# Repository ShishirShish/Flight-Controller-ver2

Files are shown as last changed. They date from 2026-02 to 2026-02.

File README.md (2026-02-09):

🛩️ SEC Flight Controller (Dual-Computer Architecture)

This repository contains the hardware design of a second-generation (SEC) Flight Controller, featuring a dual-microcontroller architecture with clear separation between real-time flight control and navigation / sensor processing.
The design emphasizes determinism, fault isolation, clean power domains, and scalable peripherals, inspired by aerospace and safety-critical embedded systems.

🧠 System Architecture Overview
Battery / Power
      |
      v
+------------------+
| Power Management |
+------------------+
        |
        +-------------------+
        |                   |
        v                   v
+----------------+   +----------------+
| Flight Control |   | Navigation     |
| Computer (FCC) |<->| Computer (NAVC)|
+----------------+   +----------------+
        |                   |
        v                   v
   Actuators / PWM       Sensors / GPS

🔹 Major Subsystems

1️⃣ Power Subsystem
Battery input up to 26 V
Precision current sense resistor (10 mΩ)
INA219 voltage / current / power monitoring (I²C)
High-current buck regulator (5 V rail)
Dedicated 3.3 V LDO for digital and sensor domains
SGND / PGND separation for noise control
Power-good, enable, and status monitoring

2️⃣ Flight Control Computer (FCC)

Role:
Real-time flight control, actuator outputs, and deterministic tasks.

MCU:
STM32F2 / STM32F4-class MCU
Key Responsibilities
PWM generation for ESCs / servos
Hard real-time control loops
Command interface to NAVC
External SPI flash for logging/config
EEPROM for configuration storage

Key Interfaces
UART (FCC ↔ NAVC)
I²C (shared / isolated buses)
SPI (external flash)
USB (programming + debug)
SWD debug header

3️⃣ Navigation Computer (NAVC)

Role:
Sensor fusion, navigation, and high-level state estimation.

MCU:
STM32F405RG-class MCU
Connected Sensors
IMU (Accelerometer + Gyroscope)
Magnetometer
Absolute pressure sensor (barometer)
Temperature sensor
GNSS (u-blox MAX-8Q)

Key Features
Dedicated sensor I²C bus
Interrupt-driven IMU & MAG
GNSS backup battery support
Independent boot and reset control
Debug UART via USB-to-UART bridge

🔁 FCC ↔ NAVC Communication
UART (bi-directional command & telemetry)
I²C (optional shared peripherals)
GPIO handshake lines
Series resistors for signal integrity and isolation

This separation allows:
Deterministic control on FCC
Computationally heavier navigation on NAVC
Easier fault containment and debugging

🔌 Peripherals & Interfaces
FCC Peripherals
PCA9685 PWM driver (16-channel)
External SPI flash memory
I²C EEPROM
Multiple UART expansion headers
ADC inputs
Servo / ESC connectors (5 V tolerant)
NAVC Peripherals
IMU + Magnetometer
Barometer + Temperature sensor
GNSS module with SMA antenna
EEPROM
Debug and telemetry UARTs

🧪 Clocking & Reset Strategy
High-speed external crystals (25 MHz) for both MCUs
Separate reset switches for FCC and NAVC
Boot-mode selection via hardware switches
Internal NRST pull-ups used where applicable

🛠️ Programming & Debug
USB-FS programming support
Dedicated SWD headers for FCC and NAVC
USB-to-UART bridges for runtime debug
Jumper-selectable USB VBUS routing

📐 Design Considerations
Clear power-domain separation
Extensive local decoupling
Ferrite bead filtering for VDDA
Series resistors on inter-MCU signals
EMI-aware sensor and GNSS routing
Designed with flight safety and expandability in mind

🧰 Tools Used
KiCad EDA 9.0.6
STM32 Reference Manuals & AN2606
Sensor manufacturer datasheets
Aerospace-style schematic partitioning

🚀 Intended Applications
Advanced UAV / drone platforms
Research flight controllers
Navigation & sensor-fusion experimentation
Safety-critical embedded system studies
FCC / NAVC split-architecture learning

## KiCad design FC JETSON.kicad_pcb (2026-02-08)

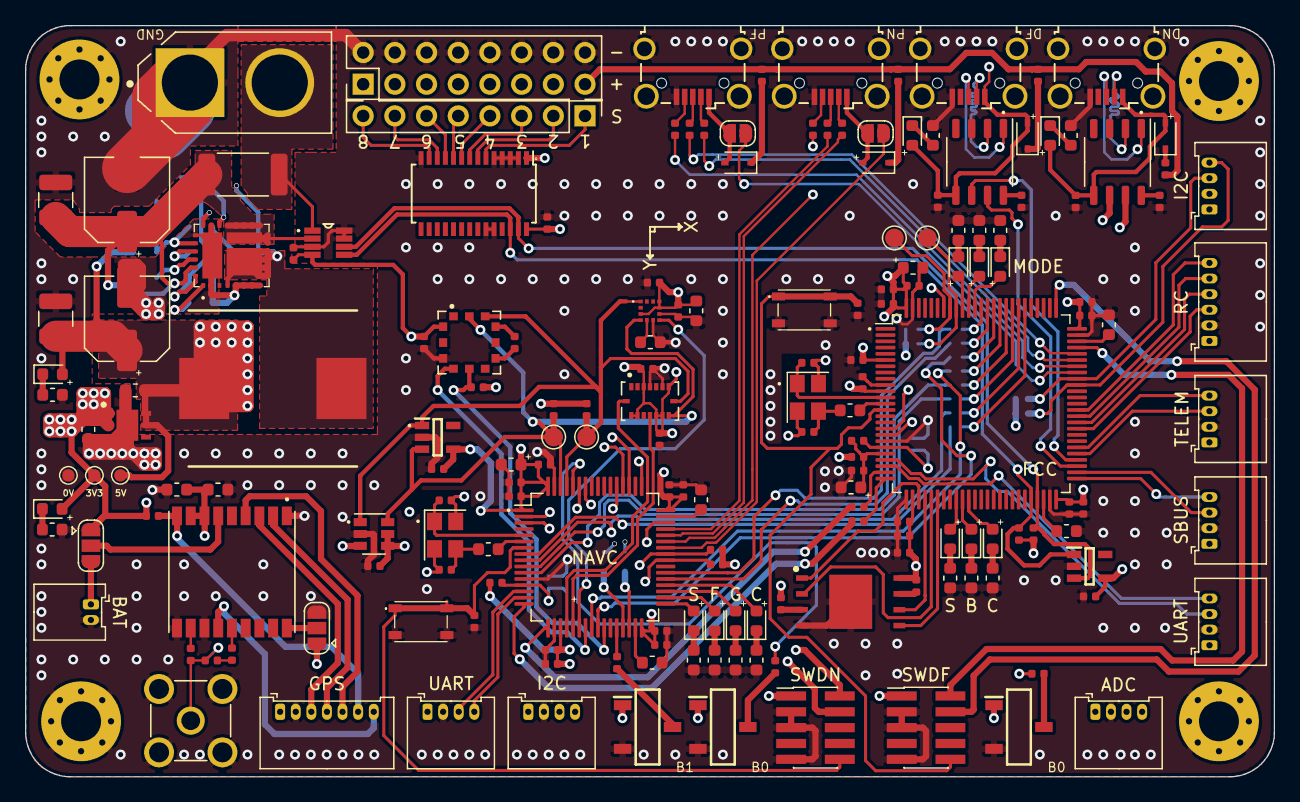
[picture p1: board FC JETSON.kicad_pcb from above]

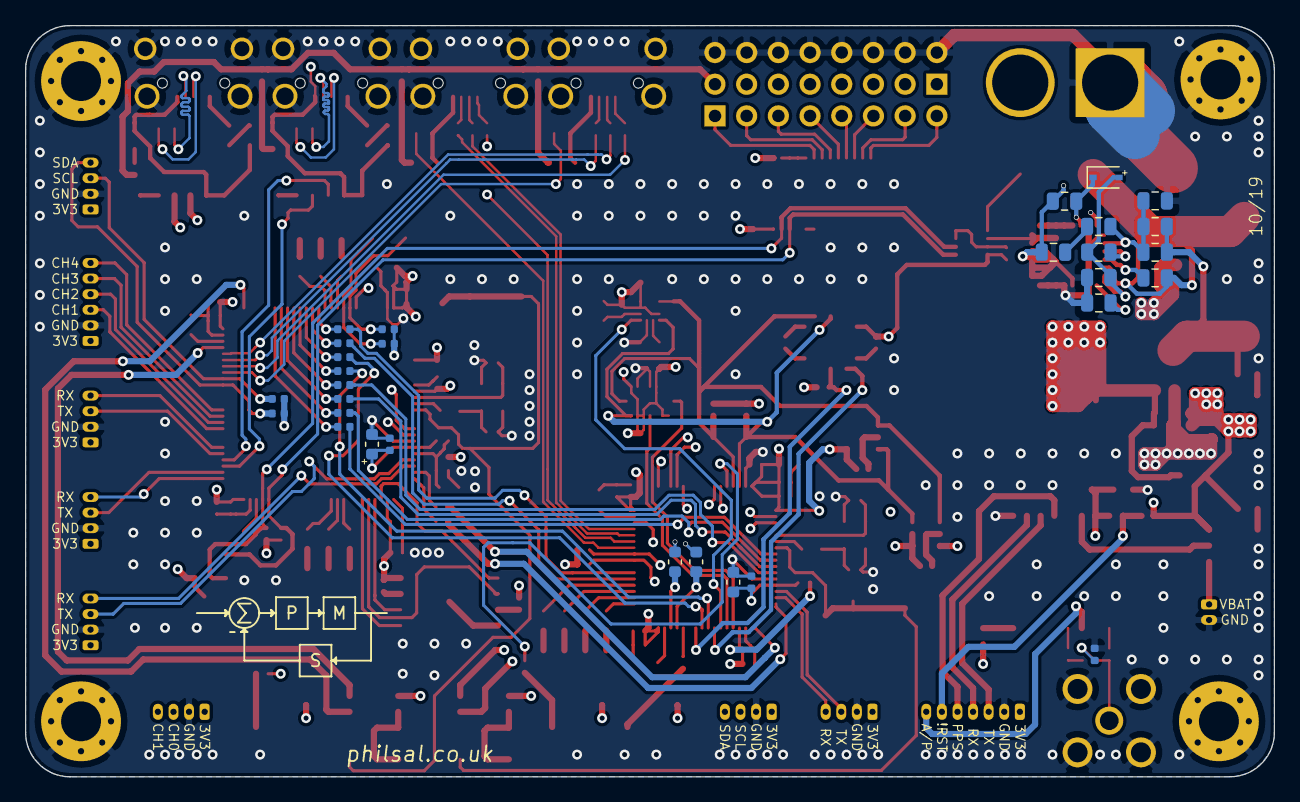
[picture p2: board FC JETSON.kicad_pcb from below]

Board: 4 copper layers, 100.1 x 60.2 mm, 211 parts (30 on the bottom side), 174 nets.

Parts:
5V, 5V#2, 5V#3: TestPoint_Pad_D1.0mm
ADC: Conn_01x04; Molex_PicoBlade_53048-0410_1x04_P1.25mm_Horizontal
ANT1: 5-1814832-1; TE_5-1814832-1
BAT: Conn_01x02; Molex_PicoBlade_53048-0210_1x02_P1.25mm_Horizontal
BAT1: XT60-M; AMASS_XT60-M
C1, C8: 100u; C_Elec_6.3x7.7
C2, C9: 47u; C_1210_3225Metric
C3, C4: 2u2; C_0805_2012Metric
C5, C6: 100n; C_0805_2012Metric
C7: 4n7; C_0805_2012Metric
C10, C16, C17, C18, C19, C20, C21, C22, C23, C24, C25, C26, C28, C30, C31, C34, C35, C36, C40, C41, C42, C43, C44, C45, C46, C47, C48, C49, C51, C54, C55, C56, C58, C60, C61, C63, C68, C69, C70, C71: 100n; C_0402_1005Metric
C11, C12, C15, C39, C62: 10u; C_0603_1608Metric
C13, C14, C37, C38: 2u2; C_0603_1608Metric
C27, C29, C50, C64, C65: 1u; C_0603_1608Metric
C32, C33, C52, C53: 10p; C_0402_1005Metric
C57: 1n; C_0402_1005Metric
C59: 220n; C_0603_1608Metric
C66: 22p; C_0402_1005Metric
C67: 10n; C_0402_1005Metric
D1, D2, D3, D4, D5: SD103AWS; D_SOD-323
FB1, FB2, FB3, FB4, FB5, FB6: Ferrite_Bead_Small; L_0402_1005Metric
FCC: STM32H753VITx; LQFP-100_14x14mm_P0.5mm
GPS: Conn_01x07; Molex_PicoBlade_53048-0710_1x07_P1.25mm_Horizontal
HSE1, HSE2: 25MHz; Crystal_SMD_Abracon_ABM8G-4Pin_3.2x2.5mm
I2C, I2C#2: Conn_01x04; Molex_PicoBlade_53048-0410_1x04_P1.25mm_Horizontal
JP1, JP2: SolderJumper_2_Open; SolderJumper-2_P1.3mm_Open_RoundedPad1.0x1.5mm
JP3: SolderJumper_3_Open; SolderJumper-3_P1.3mm_Open_RoundedPad1.0x1.5mm
JP4: Jumper_3_Open; SolderJumper-3_P1.3mm_Open_RoundedPad1.0x1.5mm
L1: 15u; INDPM135125X650N
L2: 27n; L_0402_1005Metric
LED1, LED2, LED13, LED14: G; LED_0603_1608Metric
LED3, LED4, LED9, LED10: R; LED_0603_1608Metric
LED5, LED11: Y; LED_0603_1608Metric
LED6, LED7, LED8, LED12: B; LED_0603_1608Metric
NAVC: STM32F405RGTx; LQFP-64_10x10mm_P0.5mm
PWM_POW1: Conn_02x08_Odd_Even; PinHeader_2x08_P2.54mm_Vertical
PWM_SIG1: 2.54mm; PinHeader_1x08_P2.54mm_Vertical
R1: 0.01; R_2512_6332Metric
R2, R3: 10k; R_0805_2012Metric
R4: 19k6; R_0805_2012Metric
R5: 6k8; R_0805_2012Metric
R6: 1k3; R_0805_2012Metric
R7, R58, R59: 560; R_0603_1608Metric
R8: 240; R_0603_1608Metric
R9, R10, R11, R12, R13, R14, R28, R29, R30, R31: 4k7; R_0402_1005Metric
R15, R16, R17, R33, R34, R35: 330; R_0603_1608Metric
R18, R19, R20, R36: 100; R_0603_1608Metric
R21: 47; R_0402_1005Metric
R22, R24, R25, R26, R27, R37, R38: 10k; R_0402_1005Metric
R23, R32: 620; R_0603_1608Metric
R39, R40, R41, R42, R43, R44, R45, R46, R47, R48, R49: 10; R_0402_1005Metric
R50, R51: 0; R_0603_1608Metric
R52, R53, R55, R56: 22; R_0402_1005Metric
R54, R57: 560; R_0402_1005Metric
RC: Conn_01x06; Molex_PicoBlade_53048-0610_1x06_P1.25mm_Horizontal
REG1: MIC26903YJL-TR; MIC24054YJLTR
REG2: LD39200PU33R; SON95P300X300X100-7N-D
SBUS: Conn_01x04; Molex_PicoBlade_53048-0410_1x04_P1.25mm_Horizontal
SW1, SW5: SKRPANE010; SKRPADE010
SW2, SW3, SW4: TDD01H0SB1R; SOT175P420X230-3N
SWDF: Conn_02x05_Odd_Even; PinHeader_2x05_P1.27mm_Vertical_SMD
SWDN: Conn_02x05_Odd_Even; PinHeader_2x05_P1.27mm_Vertical_SMD
TELEM: Conn_01x04; Molex_PicoBlade_53048-0410_1x04_P1.25mm_Horizontal
TP1, TP2, TP3, TP4: I2C1; TestPoint_Pad_D1.5mm
U1: INA219AIDCNR; SOT65P280X145-8N
U2: PCA9685PW; TSSOP-28_4.4x9.7mm_P0.65mm
U3, U9: 24CW1280T-I_OT; SOT95P280X145-5N
U4: W25N01GVZEIG_TR; SON127P800X600X80-9N-D
U5: BMI088; PQFN50P450X300X100-16N
U6: TMP100; SOT-23-6
U7: MPRLS0025PA00001A; XDCR_MPRLS0025PA00001A
U8: IIS2MDCTR
U10: u-blox MAX-8Q; GPS18P-SMD-1.1-10X9.6MM
U11, U12: otter:CH330; SSOP-8_3.9x5.05mm_P1.27mm
UART: Conn_01x04; Molex_PicoBlade_53048-0410_1x04_P1.25mm_Horizontal
UART#2: Conn_01x04; Molex_PicoBlade_53048-0410_1x04_P1.25mm_Horizontal
USB1, USB2, USB3, USB4: USB_B_Micro; USB_Micro-B_Wuerth_629105150521_CircularHoles

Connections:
+3V3: 5V#2.1, ADC.1, C10.1, C12.1, C15.1, C16.1, C17.1, C18.1, C19.1, C20.1, C21.1, C22.1, C23.1, C24.1, C25.1, C26.1, C34.1, C35.1, C36.2, C39.1, C40.1, C41.1, C42.1, C43.1, C44.1, C45.1, C46.1, C47.1, C48.1, C54.1, C55.1, C56.1, C58.1, C60.1, C61.1, C62.1, C63.1, C64.1, C65.1, FB1.2, FB2.2, FCC.6, FCC.11, FCC.27, FCC.50, FCC.75, FCC.100, GPS.1, I2C.1, I2C#2.1, JP3.1, JP4.1, LED2.2, NAVC.1, NAVC.19, NAVC.32, NAVC.48, NAVC.64, R9.1, R10.1, R11.1, R12.1, R13.1, R14.1, R24.1, R25.1, R28.1, R29.1, R30.1, R31.1, R37.1, R38.1, RC.1, REG2.1, REG2.2, SBUS.1, SW2.1, SW3.1, SW4.1, SWDF.1, SWDN.1, TELEM.1, U1.4, U2.1, U2.28, U3.4, U4.8, U5.3, U5.7, U5.10, U5.11, U5.14, U5.15, U6.3, U6.4, U6.5, U7.12, U8.3, U8.9, U8.10, U9.4, U10.7, U10.8, UART.1, UART#2.1
+5V: 5V.1, C7.1, C8.1, C9.1, C11.1, FB3.1, FB4.1, FB5.1, FB6.1, L1.2, LED1.2, PWM_POW1.1, PWM_POW1.3, PWM_POW1.5, PWM_POW1.7, PWM_POW1.9, PWM_POW1.11, PWM_POW1.13, PWM_POW1.15, R5.1, REG2.5, REG2.6
ADC3_0_FCC: ADC.3, FCC.17
ADC3_1_FCC: ADC.4, FCC.18
BAR_NRST_NAVC: NAVC.26, R37.2, U7.8
BOOT0_FCC: FCC.94, R22.2
BOOT0_NAVC: NAVC.60, R26.2
BOOT1_NAVC: NAVC.28, R27.2
GND: 5V#3.1, ADC.2, ANT1.2, ANT1.3, ANT1.4, ANT1.5, BAT.2, BAT1.1, C1.2, C2.2, C3.2, C4.2, C8.2, C9.2, C10.2, C11.2, C12.2, C13.2, C14.2, C15.2, C16.2, C17.2, C18.2, C19.2, C20.2, C21.2, C22.2, C23.2, C24.2, C25.2, C26.2, C27.2, C28.2, C29.2, C30.2, C31.2, C32.2, C33.2, C34.2, C35.2, C36.1, C37.2, C38.2, C39.2, C40.2, C41.2, C42.2, C43.2, C44.2, C45.2, C46.2, C47.2, C48.2, C49.2, C50.2, C51.2, C52.2, C53.2, C54.2, C55.2, C56.2, C58.2, C59.2, C60.2, C61.2, C62.2, C63.2, C64.2, C65.2, C67.2, C68.1, C69.1, C70.1, C71.1, FCC.10, FCC.19, FCC.26, FCC.49, FCC.74, FCC.99, GPS.2, HSE1.2, HSE1.4, HSE2.2, HSE2.4, I2C.2, I2C#2.2, JP3.3, NAVC.12, NAVC.18, NAVC.63, PWM_POW1.2, PWM_POW1.4, PWM_POW1.6, PWM_POW1.8, PWM_POW1.10, PWM_POW1.12, PWM_POW1.14, PWM_POW1.16, R6.1, R7.1, R8.1, R15.1, R16.1, R17.1, R18.1, R19.1, R20.1, R33.1, R34.1, R35.1, R36.1, R58.1, R59.1, RC.2, REG1.2, REG1.5, REG1.6, REG1.7, REG1.8, REG1.21, REG1.23, REG1.31, REG2.3, REG2.7, SBUS.2, SW1.3, SW1.4, SW2.2, SW3.2, SW4.2, SW5.3, SW5.4, SWDF.3, SWDF.5, SWDF.9, SWDN.3, SWDN.5, SWDN.9, TELEM.2, U1.3, U1.7, U1.8, U2.2, U2.3, U2.4, U2.5, U2.14, U2.23, U2.24, U3.2, U4.4, U4.9, U5.4, U5.6, U6.2, U7.10, U8.6, U8.8, U9.2, U10.1, U10.10, U10.12, U11.3, U12.3, UART.2, UART#2.2, USB1.5, USB1.6, USB2.5, USB2.6, USB3.5, USB3.6, USB4.5, USB4.6
GPIO_A_FCC: FCC.81, R40.2
GPIO_A_NAVC: NAVC.8, R40.1
GPIO_B_FCC: FCC.82, R41.2
GPIO_B_NAVC: NAVC.9, R41.1
GPIO_C_FCC: FCC.83, R42.2
GPIO_C_NAVC: NAVC.10, R42.1
GPIO_D_FCC: FCC.84, R43.2
GPIO_D_NAVC: NAVC.11, R43.1
GPIO_E_FCC: FCC.85, R44.2
GPIO_E_NAVC: NAVC.24, R44.1
GPIO_F_FCC: FCC.86, R45.2
GPIO_F_NAVC: NAVC.25, R45.1
GPIO_G_FCC: FCC.87, R46.2
GPIO_G_NAVC: NAVC.37, R46.1
GPIO_H_FCC: FCC.88, R47.2
GPIO_H_NAVC: NAVC.38, R47.1
GPS_BAT_BACKUP: JP4.2, U10.6
GPS_LNA_EN_NAVC: GPS.7, NAVC.2, U10.13
GPS_NRST_NAVC: GPS.6, NAVC.3, R38.2, U10.9
GPS_PPS_NAVC: GPS.5, NAVC.53, U10.4
HSE_IN_FCC: C32.1, FCC.12, HSE1.1
HSE_IN_NAVC: C52.1, HSE2.1, NAVC.5
HSE_OUT_FCC: FCC.13, R23.1
HSE_OUT_NAVC: NAVC.6, R32.1
I2C1_SCL_FCC: FCC.92, R9.2, R50.2, TP1.1
I2C1_SCL_NAVC: NAVC.61, R28.2, TP3.1, U5.8, U6.1, U7.3, U8.1, U9.1
I2C1_SDA_FCC: FCC.93, R10.2, R51.2, TP2.1
I2C1_SDA_NAVC: NAVC.62, R29.2, TP4.1, U5.9, U6.6, U7.2, U8.4, U9.3
I2C2_SCL_FCC: FCC.46, R11.2, U1.5, U2.26, U3.1
I2C2_SCL_NAVC: NAVC.29, R50.1
I2C2_SDA_FCC: FCC.47, R12.2, U1.6, U2.27, U3.3
I2C2_SDA_NAVC: NAVC.30, R51.1
I2C3_SCL_FCC: FCC.67, I2C.3, R13.2
I2C3_SCL_NAVC: I2C#2.3, NAVC.41, R30.2
I2C3_SDA_FCC: FCC.66, I2C.4, R14.2
I2C3_SDA_NAVC: I2C#2.4, NAVC.40, R31.2
INT_ACC_NAVC: NAVC.20, U5.16
INT_BAR_NAVC: NAVC.23, U7.9
INT_GYR_NAVC: NAVC.21, U5.12
INT_MAG_NAVC: NAVC.22, U8.7
LED_A_FCC: FCC.34, LED3.2
LED_A_NAVC: LED9.2, NAVC.33
LED_B_FCC: FCC.35, LED4.2
LED_B_NAVC: LED10.2, NAVC.34
LED_C_FCC: FCC.36, LED5.2
LED_C_NAVC: LED11.2, NAVC.35
LED_D_FCC: FCC.89, LED6.2
LED_D_NAVC: LED12.2, NAVC.36
LED_E_FCC: FCC.90, LED7.2
LED_F_FCC: FCC.91, LED8.2
NRST_FCC: C31.1, FCC.14, SW1.1, SW1.2, SWDF.10
NRST_NAVC: C49.1, NAVC.7, SW5.1, SW5.2, SWDN.10
unnamed: ANT1.1, C66.1, C67.1, L2.2
unnamed: C3.1, REG1.1
unnamed: C4.1, D1.2, R3.2, REG1.28
unnamed: C6.2, R4.1
unnamed: C13.1, FCC.48
unnamed: C14.1, FCC.73
unnamed: C33.1, HSE1.3, R23.2
unnamed: C37.1, NAVC.31
unnamed: C38.1, NAVC.47
unnamed: C53.1, HSE2.3, R32.2
unnamed: C57.1, U7.6
unnamed: C57.2, U7.4
unnamed: C59.1, U8.5
unnamed: C66.2, U10.11
unnamed: C68.2, D4.2, LED13.2, U11.5, USB3.1
unnamed: C69.2, U11.8
unnamed: C70.2, D5.2, LED14.2, U12.5, USB4.1
unnamed: C71.2, U12.8
unnamed: D2.1, FB3.2
unnamed: D2.2, JP1.1, USB1.1
unnamed: D3.1, FB4.2
unnamed: D3.2, JP2.1, USB2.1
unnamed: D4.1, FB5.2
unnamed: D5.1, FB6.2
unnamed: BAT.1, JP4.3
unnamed: JP3.2, U10.18
unnamed: L2.1, R39.1
unnamed: LED1.1, R7.2
unnamed: LED2.1, R8.2
unnamed: LED3.1, R15.2
unnamed: LED4.1, R16.2
unnamed: LED5.1, R17.2
unnamed: LED6.1, R18.2
unnamed: LED7.1, R19.2
unnamed: LED8.1, R20.2
unnamed: LED9.1, R33.2
unnamed: LED10.1, R34.2
unnamed: LED11.1, R35.2
unnamed: LED12.1, R36.2
unnamed: LED13.1, R58.2
unnamed: LED14.1, R59.2
unnamed: R22.1, SW2.3
unnamed: R24.2, U4.7
unnamed: R25.2, U4.3
unnamed: R26.1, SW3.3
unnamed: R27.1, SW4.3
unnamed: R39.2, U10.14
unnamed: R52.2, USB1.3
unnamed: R53.2, USB1.2
unnamed: R54.2, USB1.4
unnamed: R55.2, USB2.3
unnamed: R56.2, USB2.2
unnamed: R57.2, USB2.4
unnamed: U11.1, USB3.3
unnamed: U11.2, USB3.2
unnamed: U12.1, USB4.3
unnamed: U12.2, USB4.2
PWM_0: PWM_SIG1.1, U2.6
PWM_1: PWM_SIG1.2, U2.7
PWM_2: PWM_SIG1.3, U2.8
PWM_3: PWM_SIG1.4, U2.9
PWM_4: PWM_SIG1.5, U2.10
PWM_5: PWM_SIG1.6, U2.11
PWM_6: PWM_SIG1.7, U2.12
PWM_7: PWM_SIG1.8, U2.13
REG_BST: C5.2, D1.1, REG1.20
REG_CS: C5.1, C6.1, L1.1, REG1.4, REG1.9, REG1.10, REG1.11, REG1.12, REG1.22, REG1.29
REG_EN: R2.2, REG1.26
REG_FB: C7.2, R4.2, R5.2, R6.2, REG1.24
REG_PG: R3.1, REG1.25
REG_VIN: C1.1, C2.1, R1.1, R2.1, REG1.13, REG1.14, REG1.15, REG1.16, REG1.17, REG1.18, REG1.19, REG1.27, REG1.30, U1.2
SPI1_CS_FLASH_FCC: FCC.28, U4.1
SPI1_MISO_FCC: FCC.30, U4.2
SPI1_MOSI_FCC: FCC.31, U4.5
SPI1_SCK_FCC: FCC.29, U4.6
SWCLK_FCC: FCC.76, SWDF.4
SWCLK_NAVC: NAVC.49, SWDN.4
SWDIO_FCC: FCC.72, SWDF.2
SWDIO_NAVC: NAVC.46, SWDN.2
TIM4_CH1_FCC: FCC.59, RC.3
TIM4_CH2_FCC: FCC.60, RC.4
TIM4_CH3_FCC: FCC.61, RC.5
TIM4_CH4_FCC: FCC.62, RC.6
UART1_RX_FCC: FCC.54, U11.6
UART1_RX_NAVC: GPS.4, NAVC.59, U10.2
UART1_TX_FCC: FCC.53, U11.7
UART1_TX_NAVC: GPS.3, NAVC.58, U10.3
UART2_RX_FCC: FCC.25, R48.2
UART2_RX_NAVC: NAVC.17, R49.1
UART2_TX_FCC: FCC.24, R49.2
UART2_TX_NAVC: NAVC.16, R48.1
UART3_RX_FCC: FCC.56, TELEM.4
UART3_RX_NAVC: NAVC.52, U12.6
UART3_TX_FCC: FCC.55, TELEM.3
UART3_TX_NAVC: NAVC.51, U12.7
UART4_RX_FCC: FCC.23, UART#2.4
UART4_RX_NAVC: NAVC.15, UART.4
UART4_TX_FCC: FCC.22, UART#2.3
UART4_TX_NAVC: NAVC.14, UART.3
UART5_RX_FCC: FCC.51, SBUS.4
UART5_TX_FCC: FCC.52, SBUS.3
USB_DM_FCC: FCC.70, R53.1
USB_DM_NAVC: NAVC.44, R56.1
USB_DP_FCC: FCC.71, R52.1
USB_DP_NAVC: NAVC.45, R55.1
USB_ID_FCC: FCC.69, R54.1
USB_ID_NAVC: NAVC.43, R57.1
USB_VBUS_FCC: FCC.68, JP1.2
USB_VBUS_NAVC: JP2.2, NAVC.42
VDDA_FCC: C27.1, C28.1, FB1.1, FCC.21, R21.2
VDDA_NAVC: C50.1, C51.1, FB2.1, NAVC.13
VIN+: BAT1.2, R1.2, U1.1
VREF+_FCC: C29.1, C30.1, FCC.20, R21.1
